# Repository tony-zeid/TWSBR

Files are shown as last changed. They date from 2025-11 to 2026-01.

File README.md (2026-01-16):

# Two‑Wheeled Self‑Balancing Robot (TWSBR)

PID‑controlled, two‑wheeled self‑balancing robot built on Arduino Uno with an MPU6050 IMU, motor encoders, and optional Bluetooth for parameter updates. 

## Features
- Balance via cascaded PID controllers (position → balance → heading)
- MPU6050 sensor fusion (complementary filter) for roll/pitch/yaw
- Quadrature encoder support with interrupts per motor
- Modular drivers for motors, pins, messaging, and Bluetooth
- PlatformIO project for reproducible build and upload

## Hardware
- Arduino Uno (ATmega328P)
- 2 × DC gear motors with quadrature encoders
- Dual H‑bridge motor driver (e.g. L298N/L9110S/compatible)
- IMU: MPU6050 (I²C)
- Optional HC‑05/HC‑06 Bluetooth module
- 7–12V battery pack with suitable regulator for logic and motors

### Pinout (Arduino Uno)
- Motors (PWM/direction)
	- MOT1_A: D6, MOT1_B: D5
	- MOT2_A: D10, MOT2_B: D11
- Encoders (interrupt channels)
	- ENC1_A: D3, ENC1_B: D13
	- ENC2_A: D2, ENC2_B: D12
- Bluetooth (optional)
	- BT_RX_PIN: D7, BT_TX_PIN: D8
- I²C (MPU6050)
	- SDA: A4, SCL: A5

Refer to the constants in include/pins.h if you change wiring.

## Wiring Table
| Subsystem | Signal | Arduino Pin | Constant | Notes |
|---|---|---|---|---|
| Motor driver | Motor 1 A (PWM/dir) | D6 | MOT1_A | Connect to driver input for M1 phase A |
| Motor driver | Motor 1 B (PWM/dir) | D5 | MOT1_B | Connect to driver input for M1 phase B |
| Motor driver | Motor 2 A (PWM/dir) | D10 | MOT2_A | Connect to driver input for M2 phase A |
| Motor driver | Motor 2 B (PWM/dir) | D11 | MOT2_B | Connect to driver input for M2 phase B |
| Encoder 1 | Channel A (INT1) | D3 | ENC1_A | Attach to encoder A; interrupt on rising edge |
| Encoder 1 | Channel B | D13 | ENC1_B | Direction sense |
| Encoder 2 | Channel A (INT0) | D2 | ENC2_A | Attach to encoder A; interrupt on rising edge |
| Encoder 2 | Channel B | D12 | ENC2_B | Direction sense |
| Bluetooth (optional) | Module TX → Uno | D7 | BT_RX_PIN | HC‑05 TX to Uno D7 |
| Bluetooth (optional) | Module RX ← Uno | D8 | BT_TX_PIN | Use resistor divider for HC‑05 RX |
| IMU MPU6050 | SDA | A4 | — | I²C data |
| IMU MPU6050 | SCL | A5 | — | I²C clock |
| IMU MPU6050 | VCC | 3.3V/5V | — | Depends on breakout (often 5V tolerant) |
| IMU/Logic | GND | GND | — | Common ground for all modules |

## Project Structure
- include/
	- IMU_functions.h — IMU addresses and public IMU API
	- bluetooth.h — Bluetooth helpers (initialise/read)
	- command.h — command handling and parameter getters
	- control_sys.h — PID gains and control loop APIs
	- messages.h — serial/Bluetooth printing utilities
	- motor_driver.h — motor actuation API
	- pins.h — pin definitions and `setupPins()`
- src/
	- IMU_functions.cpp — IMU initialisation, sensitivity config, readout, error calibration
	- bluetooth.cpp — parameter getters and Bluetooth stubs
	- control_sys.cpp — PID controllers and cascade to motor outputs
	- main.cpp — application entrypoint, run modes, telemetry
	- messages.cpp — printing helpers
	- motor_driver.cpp — PWM and direction control with fail‑safes
	- pins.cpp — pin modes and interrupt attachment
- platformio.ini — board and framework configuration

## Build, Upload, Monitor
This project uses PlatformIO. In VS Code with the PlatformIO extension:

```bash
platformio run                 # Build
platformio run --target upload # Upload to Arduino Uno
platformio device monitor -b 19200 # Open serial monitor
```

Serial baud is 19200 (required for stable MPU6050 operation in this project). Bluetooth baud is 9600 (HC‑05/HC‑06 default).

## Command Interface
The firmware accepts simple newline‑terminated commands from either the Serial Monitor (19200 baud) or the Bluetooth link (9600 baud). Commands update run mode, debug mode, PID parameters, and telemetry rate at runtime.

### Commands
- Run mode
	- `mode 0` — measure only
	- `mode 1` — run controllers (no motor drive)
	- `mode 2` — full operation (drive motors)
- Debug/print mode
	- `debug 0` — compact output (roll pitch yaw, space‑separated)
	- `debug 1` — verbose output (all diagnostics and parameters)
- Telemetry rate
	- `rate <cycles>` — print every N cycles (applies to current debug mode independently)
- Position PID
	- `poskp <value>` — proportional gain
	- `poski <value>` — integral gain
	- `poskd <value>` — derivative gain
	- `posset <value>` — setpoint
- Balance PID
	- `balkp <value>` — proportional gain
	- `balki <value>` — integral gain
	- `balkd <value>` — derivative gain
	- `balset <value>` — setpoint
- Heading PID
	- `hdgkp <value>` — proportional gain
	- `hdgki <value>` — integral gain
	- `hdgkd <value>` — derivative gain
	- `hdgset <value>` — setpoint
- IMU Calibration
	- `cal` — calibrate IMU (robot upright on wheels)
	- `cal_inv` — calibrate IMU (robot upside-down on flat top)
- Status
	- `status` — print a simple OK message

**Note:** All parameter changes (PID gains, modes, rates) and calibration results are automatically saved to EEPROM and persist across reboots.

### Examples
```
# Serial Monitor – verbose with default rate (every 500 cycles):
debug 1
mode 2
balkp 2.0

# Serial Monitor – compact output for tuning (every 10 cycles):
debug 0
rate 10
mode 2

# Bluetooth – switch to verbose, adjust a parameter:
debug 1
poskp 0.5
rate 100
```

## Run Modes & Debug Modes
`runMode` controls algorithm behaviour:
- 0 — Measure only (reads IMU and prints diagnostics)
- 1 — Run controllers (compute control signals, do not drive motors)
- 2 — Drive motors (full operation with motor control)

`debugMode` controls telemetry output:
- 0 — **Compact**: prints roll, pitch, yaw only (space‑separated, one per line) – useful for live tuning via terminal or data logging
- 1 — **Verbose**: prints all parameters, control signals, motor outputs, and diagnostics – useful for development and debugging

Each debug mode has its own independent `dataRate` (cycles per print). Use `rate` command to tune telemetry frequency per mode.

## Control Parameters
PID gains live in include/control_sys.h:
- Balance (critical): `BAL_KP`, `BAL_KI`, `BAL_KD`, `BAL_SETPOINT`
- Position: `POS_KP`, `POS_KI`, `POS_KD`, `POS_SETPOINT`
- Heading: `HDG_KP`, `HDG_KI`, `HDG_KD`, `HDG_SETPOINT`

At runtime the firmware exposes read‑only parameter blocks via:
- `getPosParam()`, `getBalParam()`, `getHdgParam()`

Bluetooth hooks (`readBtSerial()`, `updateVar()`) are scaffolded for future use but disabled by default (SoftwareSerial lines commented). To experiment, enable the commented SoftwareSerial initialisation and message prints in src/main.cpp and src/messages.cpp.

## IMU Setup and Calibration
On startup the firmware:
1. `imuInitialise()` — wakes the IMU and resets it
2. `imuConfigSensitivity()` — sets accel/gyro full‑scale ranges (configurable via `ACCEL_FSR` and `GYRO_FSR` in `include/IMU_functions.h`)
3. Calibration is now done via command, not automatically on boot

### Manual Calibration Commands
**Normal calibration (robot upright on wheels):**
```
cal
```
Keep the robot completely still and level for 2 seconds. Errors are saved to EEPROM and persist across reboots.

**Upside-down calibration (robot on flat top):**
```
cal_inv
```
Place robot on its flat top surface, level and still. This inverts accelerometer error measurements so the robot works correctly when flipped right-side-up. After calibration, flip the robot and restart for normal operation.

### Configuring IMU Full-Scale Ranges
Edit `include/IMU_functions.h` to change sensor ranges:
- `ACCEL_FSR`: 0 (±2g), 1 (±4g), 2 (±8g), 3 (±16g)
- `GYRO_FSR`: 0 (±250°/s), 1 (±500°/s), 2 (±1000°/s), 3 (±2000°/s)

Divisors update automatically when you change these values.

## PID Tuning Guide (Ziegler-Nichols Method)

### Prerequisites
Before tuning:
1. Ensure hardware is verified (encoders working, motors correct direction)
2. Calibrate IMU using `cal` or `cal_inv` command
3. Lift wheels off ground for initial testing

### Step 1: Find Critical Gain (Proportional Only)
Start with pure proportional control:
```
balkp 1.0
balki 0.0
balkd 0.0
debug 0
rate 10
mode 2
```

Gradually increase `balkp` by 0.5 until the robot oscillates **steadily** (constant amplitude):
- Too low: Robot falls immediately
- Critical gain (`Kp_crit`): Sustained oscillations without growing or decaying
- Too high: Violent oscillations that grow rapidly

**Record:**
- `Kp_crit` = value where oscillations are steady
- `T_osc` = period between peaks (count cycles, multiply by sample time)

### Step 2: Calculate PID Gains
Using Ziegler-Nichols PID formula:
```
Kp = 0.6 × Kp_crit
Ki = 1.2 × Kp_crit / T_osc
Kd = 0.075 × Kp_crit × T_osc
```

**Example:**
If `Kp_crit = 5.0` and `T_osc = 0.5s`:
```
balkp 3.0    # 0.6 × 5.0
balki 12.0   # 1.2 × 5.0 / 0.5
balkd 0.19   # 0.075 × 5.0 × 0.5
```

### Step 3: Fine-Tune
Apply calculated gains and observe:
- **Too much overshoot (>20°)?** Reduce `balkp` by 10-20%
- **Steady-state error (drifts)?** Increase `balki` slightly (by ~0.02)
- **High-frequency oscillations/chatter?** Increase `balkd` for damping
- **Sluggish response?** Increase `balkp` by 10%

### Recommended Starting Points
If you want to skip the calculation:
```
balkp 2.5    # Moderate response
balki 0.1    # Prevents drift
balkd 0.05   # Light damping
```

Then tune by feel:
- Increase `balkp` until it responds quickly but doesn't overshoot badly
- Add `balki` only if robot drifts slowly when balanced
- Increase `balkd` if robot oscillates after disturbance

### Quick Test Commands
```
# Test step response
balset 2.0   # Lean forward 2°, should recover smoothly

# Test disturbance rejection
# Gently push robot, should return to vertical in < 0.5s

# Monitor performance
debug 1
rate 1       # Print every cycle for detailed analysis
```

## Code Conventions
- Functions/variables: lowerCamelCase (e.g. `runMode`, `setupPins`, `balanceControl`)
- Constants/macros: UPPER_SNAKE_CASE (e.g. `MOT1_A`, `IMU_GYRO_DATA`)
- Types: PascalCase

## Safety Features
- **Safety Cutoff:** Motors automatically cut if tilt exceeds ±45° (prevents damage during pickup or falls)
- **Motor Clamping:** PWM outputs clamped to 0–255
- **Direction Safety:** Direction pins clear before switching to prevent shoot-through
- **Encoder Deadband:** ±2 tick deadband prevents noise-induced motor chatter

**Testing Safety:**
- Lift wheels off ground during initial tests
- Ensure power rails are stable; brown‑outs can cause runaway behaviour
- Use foam padding when testing autonomous balance

## Memory Usage and Optimization Notes

**Current RAM Usage: ~88% (1808/2048 bytes)**

The Arduino Uno has only 2KB of RAM, and this project uses:
- **~450 bytes**: Arduino libraries (Serial, Wire/I²C, SoftwareSerial)
- **~200 bytes**: Global variables (control arrays, IMU state, motor state)
- **~1000 bytes**: Arduino core overhead (timers, interrupts, system buffers)
- **~240 bytes free**: Available for stack during runtime

### Recent Optimizations
Several RAM optimizations have been applied to reduce memory pressure:

1. **String → char array conversion**: Replaced `String` objects with fixed-size `char[64]` buffers for serial/Bluetooth input (~60-80 bytes saved)
2. **Bit-packed mode flags**: Packed `runMode`, `debugMode`, and `printData` into a single byte using bit fields (2 bytes saved)
3. **Local variables for controller outputs**: Changed `posOut`, `balOut`, `hdgOut` from static globals to local variables (12 bytes saved)
4. **Direct AVR EEPROM access**: Replaced Arduino EEPROM library with `<avr/eeprom.h>` functions (eliminates library overhead)

**Total RAM savings: ~95 bytes** (from 95.3% → 88.7% usage including safety cutoff feature)

### IMU Configuration
The IMU full-scale ranges are now configurable at compile-time in `include/IMU_functions.h`:
- `ACCEL_FSR`: 0-3 (±2g, ±4g, ±8g, ±16g) - currently set to 2 (±8g)
- `GYRO_FSR`: 0-3 (±250°/s, ±500°/s, ±1000°/s, ±2000°/s) - currently set to 2 (±1000°/s)

Divisors are automatically calculated based on these settings.

### EEPROM Implementation
This project uses direct AVR EEPROM functions (`eeprom_read_byte()` and `eeprom_write_byte()` from `<avr/eeprom.h>`) instead of the Arduino EEPROM library. This approach:
- Eliminates library RAM overhead
- Provides explicit control over EEPROM operations
- Saves ~50-100 bytes compared to the Arduino library

All parameters (PID gains, modes, IMU calibration) persist across reboots via EEPROM.

**Current Status:**
With 240 bytes of free stack space, there is adequate headroom for runtime operations. The control loops avoid deep recursion and large local variables, keeping stack usage minimal.

## Tuning the Control Loops

### Overview
The robot uses a cascaded control structure: **Position** → **Balance** → **Motors**. Tuning follows a bottom‑up approach starting with balance (most critical), then position and heading.

### Balance Loop (Critical)
The balance loop corrects tilt (pitch) to keep the robot upright. **Start here first.**

#### Phase 1: Controller Sanity Check (Mode 1, wheels lifted)
1. **Lift wheels off the ground** and hold robot level
2. Set `mode 1` (controllers run, motors disabled) and `debug 1` (verbose output)
3. Start with small gains: `balkp 1.0`, `balki 0.0`, `balkd 0.0`
4. **Tilt robot forward** and observe the **motor command output** in telemetry:
   - Controller should output positive PWM (trying to drive forward to correct)
   - Larger tilt → larger PWM (proportional response)
5. **Tilt robot backward** and verify opposite response (negative/reverse motor command)
6. If signs are wrong, swap motor direction pins or invert controller logic

#### Phase 2: Initial Balance Test (Mode 2, wheels on ground)
7. **Place robot on flat surface** with wheels on ground
8. Set `mode 2` (full operation, motors enabled)
9. **Hold robot upright** and release gently:
   - Robot should attempt to balance (may fall at first)
   - Observe for oscillation, divergence, or stability
10. If robot falls immediately:
    - Reduce `balkp` by 50% and retry
    - Verify motor directions are correct (both should spin same direction when tilting forward)
11. If robot oscillates slowly (growing):
    - Increase `balkp` by 20–50%
12. If robot oscillates rapidly (high frequency):
    - Reduce `balkp` or add small `balkd` (start 0.02)

#### Phase 3: Fine-Tuning
13. Once robot balances briefly (even 1–2 seconds), tune for stability:
    - Increase `balkp` until oscillation just begins, then back off 10–20%
    - Add `balki` (0.05–0.1) only if robot drifts slowly in one direction
    - Add `balkd` (0.02–0.05) if high-frequency vibration appears
14. Use compact telemetry for real-time feedback: `debug 0`, `rate 10`
15. Test by gently pushing robot forward/backward; it should recover smoothly

**Typical starting gains**: `balkp 2.0`, `balki 0.1`, `balkd 0.03` (highly robot-dependent)

### IMU Drift Issue
If IMU pitch/roll drifts after movement and doesn't return to zero:
- **Re-calibrate IMU** (keep robot level and still during startup)
- **Check complementary filter** (currently in `IMU_functions.cpp`, typically 0.98–0.99 gyro weight)
- **Gyro drift** is normal over time; re-calibration or magnetometer fusion helps

### Position Loop (Once Balance Works)
Position loop maintains forward/backward centering. The balance loop naturally provides position feedback via roll change.

1. Switch to `mode 2` with wheels still lifted (motor PWM will run but wheels won't turn much).
2. Observe whether the robot tends to "creep" forward or backward in pitch.
3. Adjust `poskp` (start ~0.5–1.0) and `poski` (~0.05) if systematic drift appears.
4. Most robots need minimal position tuning if balance loop is good.

### Heading Loop (Fine‑Tuning)
Heading loop corrects yaw. Usually requires minimal tuning for forward motion.

1. With the robot on a flat surface (wheels on ground), switch to `mode 2`.
2. Watch yaw drift; if the robot consistently turns left/right, adjust `hdgkp` and `hdgki` slightly.
3. Most setups work well with `hdgkp 1.0`, `hdgki 0.0`, `hdgkd 0.0`.

### Practical Workflow
```bash
# 1. Verify controller sign (mode 1, wheels lifted)
debug 1
mode 1
balkp 1.0
balki 0.0
balkd 0.0
# Tilt forward/backward and observe motor commands in telemetry

# 2. Initial balance test (mode 2, wheels on ground)
mode 2
# Hold upright and release; adjust balkp until stable

# 3. Switch to compact telemetry for live tuning
debug 0
rate 10

# 4. Fine-tune gains
balkp 2.0      # Adjust until oscillation just stops
balki 0.1      # Add if slow drift appears
balkd 0.03     # Add if high-frequency vibration

# 5. If IMU drifts, re-calibrate by restarting with robot level
# (or adjust complementary filter in IMU_functions.cpp)
```
rate 100
```

### Monitoring Telemetry
- **Compact mode** (`debug 0`): Three space‑separated floats per line: roll pitch yaw. Pipe to a file for post‑analysis.
  ```bash
  # Example: log data for 30 seconds at 19200 baud
  cat /dev/ttyUSB0 > data.txt &
  # ... run tuning commands ...
  # Ctrl+C to stop
  gnuplot -e "plot 'data.txt' u 2" # Plot pitch over time
  ```
- **Verbose mode** (`debug 1`): Full diagnostics; easier for real‑time observation but slower telemetry.

### If Robot Oscillates or Diverges
- **High‑frequency oscillation**: Reduce Kd or Kp; IMU noise may be coupling back.
- **Low‑frequency / growing oscillation**: Reduce Ki; integral term may be accumulating too fast.
- **Divergent (unstable)**: Cut all gains by half and restart. Check motor/encoder wiring.

### If Robot Falls Sideways
- Verify IMU calibration: run `mode 0` and confirm roll ≈ 0 when level.
- Check that motors spin in the correct directions (balance loop commands opposite motors for correction).
- Verify encoder counts are correct (see Troubleshooting).

## Troubleshooting
- No serial output: check the monitor baud is 19200.
- IMU values stuck or wild: verify SDA/SCL wiring and 5V↔3.3V compatibility of your module.
- Encoders count backwards: swap encoder B signal or invert in `inc1()/inc2()`.
- Motors spin but no balance: start tuning with balance Kp small (e.g. 2.0) and Ki/Kd near zero, then iterate.

## Acknowledgements
IMU routines adapted from Dejan Nedelkovski (howtomechatronics.com).

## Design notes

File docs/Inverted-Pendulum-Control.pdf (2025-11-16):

# Dynamics and Control of Inverted Pendulum Systems

## 1 Standard Inverted Pendulum on a Cart

### 1.1 System Description

- Cart mass: M
- Pendulum mass: m
- Pendulum length to CoM: l
- Gravity: g
- Horizontal force input: F
- x: horizontal position of the cart
- θ: pendulum angle from vertical (clockwise positive)

### 1.2 Nonlinear Equations of Motion

(M + m)¨x + ml¨θ cos θ − ml ˙θ
2
sin θ = F | (1)
mlx¨ cos θ + ml² ¨θ − mglsin θ = 0 | (2)

### 1.3 Nonlinear State-Space Model

Define state vector and input:

x =

x
x˙
θ
˙θ

, u = F

Express the system as:

x˙ =

x˙
x¨
˙θ
¨θ

= f(x, u)

To solve for ¨x and ¨θ, rewrite (1), (2) in matrix form:
M + m ml cos θ
ml cos θ ml²

| | {z | }
| D(θ)
x¨
¨θ
=

u + ml ˙θ
2
sin θ
mglsin θ

Then:
x¨
¨θ
= D(θ)

−1

u + ml ˙θ
2
sin θ
mglsin θ

Hence the nonlinear state-space model is:

x˙ =

x˙
x¨(x, u)
˙θ
¨θ(x, u)

—

## 2 Wheeled Inverted Pendulum (Self-Balancing Robot)

### 2.1 System Description

- Wheel mass: M, radius R, inertia Iw
- Pendulum mass: m, pendulum CoM length: l, inertia Ip
- Gravity: g
- Torque input: τ (applied to wheel)
- x: horizontal position of wheel
- θ: pendulum angle from vertical (clockwise positive)

### 2.2 Nonlinear Equations of Motion

M + m +

Iw
R²
x¨ + ml¨θ cos θ − ml ˙θ
2
sin θ =

τ
R

(3)

mlx¨ cos θ +

Ip + ml²
¨θ − mglsin θ = 0 | (4)

### 2.3 Nonlinear State-Space Model

Define

x =

x
x˙
θ
˙θ

, u = τ

Rewrite (3), (4) as:

D(θ) =
M + m +

Iw
R² | ml cos θ
ml cos θ | Ip + ml²
, b =
u

R + ml ˙θ
2
sin θ
mglsin θ

Then
x¨
¨θ
= D(θ)

−1b

The nonlinear state-space form is

x˙ =

x˙
x¨(x, u)
˙θ
¨θ(x, u)

—

## 3 Linearized Models and State-Space Form

### 3.1 Linearized Dynamics for Cart Pendulum

Linearize around θ = 0, ˙θ = 0:

sin θ ≈ θ, cos θ ≈ 1

Linearized equations:
M + m ml
ml ml²

x¨
¨θ
=
u

mglθ

Explicitly:

(M + m)¨x + ml¨θ = u

mlx¨ + ml² ¨θ − mglθ = 0

### 3.2 Linearized State-Space Form for Cart Pendulum

Define state:

x =

x
x˙
θ
˙θ

, u = F

The linear state-space model is:

x˙ = Ax + Bu

Where

A =

0 1 | 0 | 0
0 0 | −
| mgl M | 0
0 0 | 0 | 1

0 0 (M+m)g
| M l | 0

, B =

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
### 3.3 Linearized Dynamics for Wheeled Inverted Pendulum

Linearize around θ = 0, ˙θ = 0:

sin θ ≈ θ, cos θ ≈ 1

D =

α | ml
ml | β

with

α = M + m +

Iw
R²

, β = Ip + ml²

Linearized equations:
α | ml
ml | β x¨ ¨θ
=

u
R

mglθ

—

### 3.4 Linearized State-Space Form for Wheeled Pendulum

State vector:

x =

x
x˙
θ
˙θ

, u = τ

State-space model:

x˙ = Ax + Bu

with

A =

0 1 | 0 | 0
0 0 − | m²gl² ∆R | 0
0 0 | 0 | 1
0 0 | mglα ∆ | 0

, B =

0

β
∆R
0
−

ml
∆

where the determinant

∆ = αβ − (ml)

2

—

## 4 Controller Design

### 4.1 PID Control

For both systems, a PID controller can be used to regulate the pendulum angle:

u(t) = Kpe(t) + Ki

Z
e(t)dt + Kd

de(t)
dt , e(t) = θref − θ(t)

Tuning methods (Ziegler-Nichols, manual) apply.

### 4.2 LQR Control

Given linearized models:

x˙ = Ax + Bu, u = −Kx

The gain matrix K minimizes

J =

Z ∞

0

| x | TQx + u

TRu
dt

where Q and R are weighting matrices chosen by the designer. K is computed by solving the algebraic Riccati equation.
—

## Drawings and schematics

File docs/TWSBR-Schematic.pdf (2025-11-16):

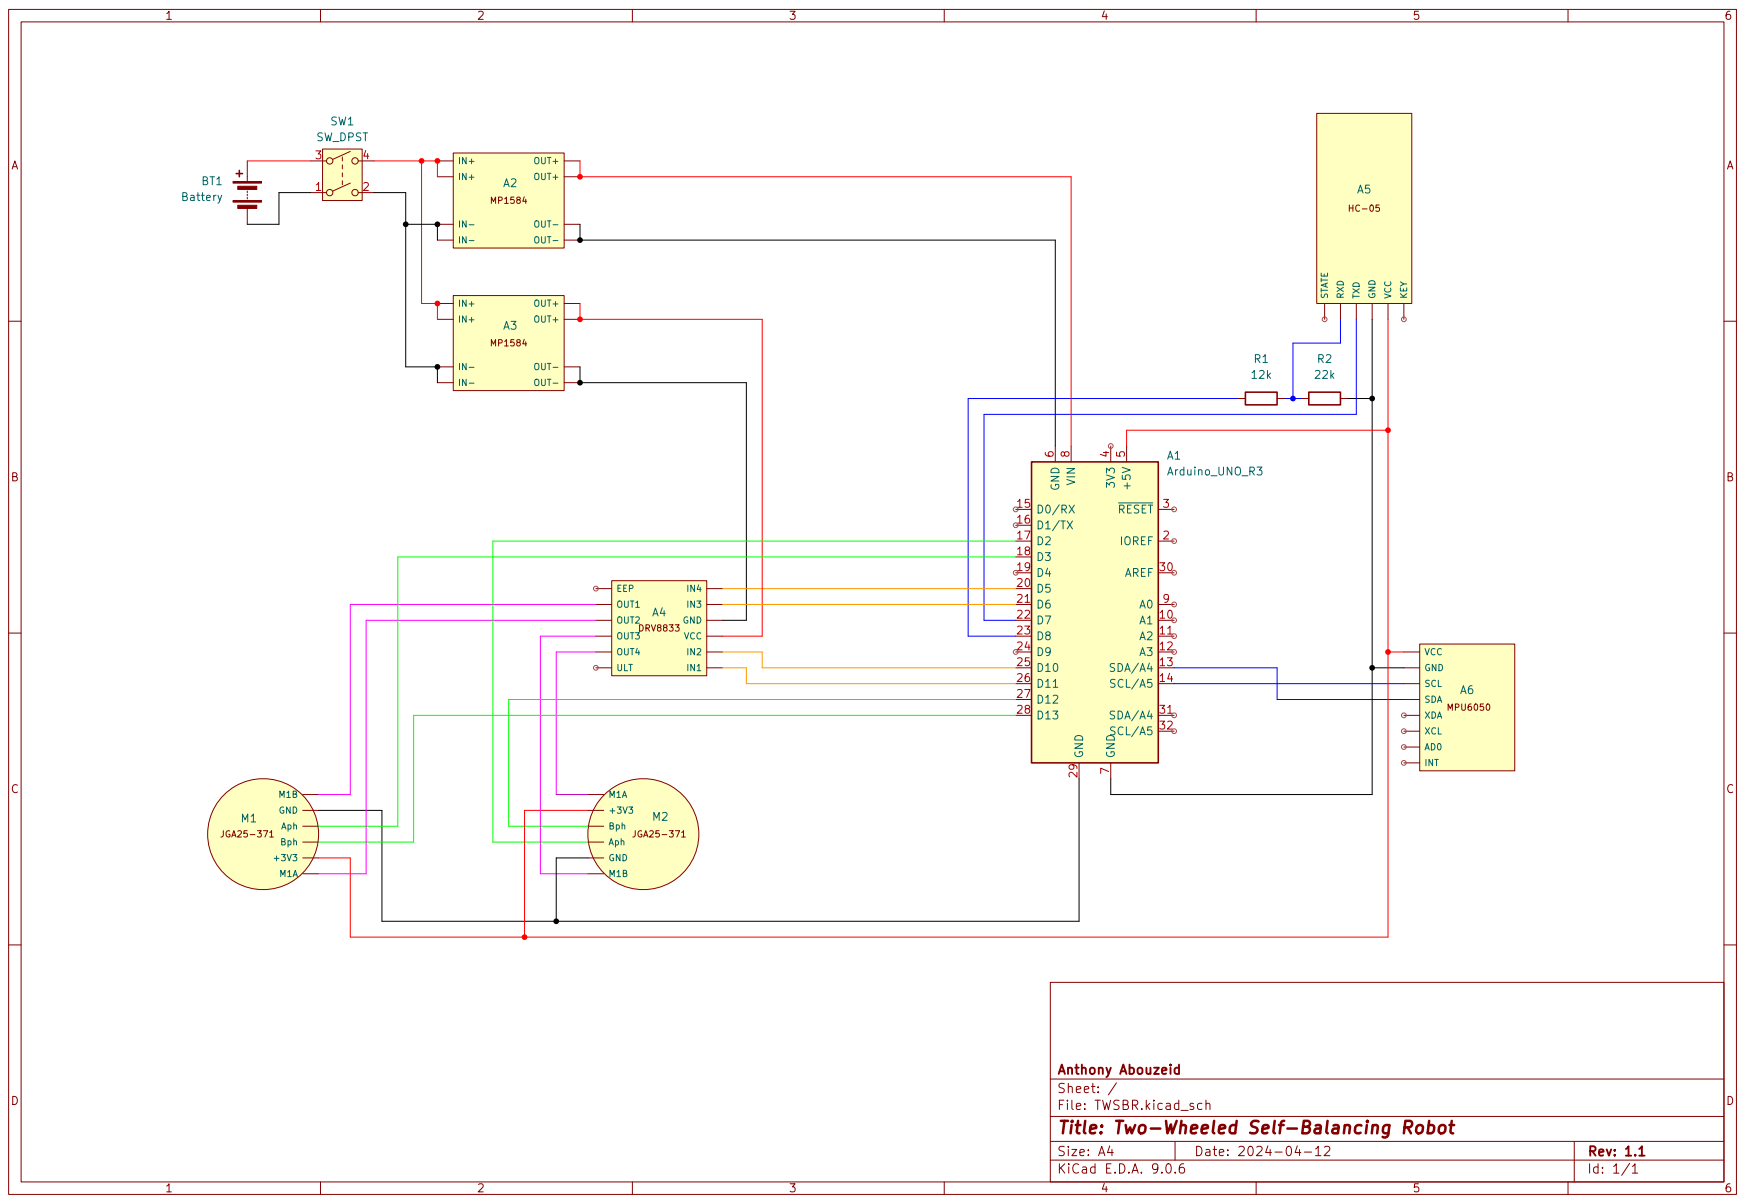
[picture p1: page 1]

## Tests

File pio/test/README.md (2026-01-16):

# TWSBR Test Suite

This directory contains tests for the TWSBR firmware.

## Test Organization

All tests are in the `test/` folder with naming conventions:
- **test_\*.cpp** — Native PC tests (command parsing, control math, validation)
- **test_hw_\*.cpp** — Arduino Uno hardware tests (EEPROM, motors, encoders, IMU)
- **test_support.\*** — Shared test infrastructure for native tests

## Running Tests

### Native tests only (PC)
```bash
platformio test -e native -v
```

### Hardware tests only (requires Arduino Uno)
```bash
platformio test -e uno -v
```

### Specific test
```bash
platformio test -e uno -f test_hw_motors -v
platformio test -e native -f test_command -v
```

## Native Test Suite

Tests for command parsing, control logic, and parameter validation—run on PC without hardware.

### Test Files

- **test_command.cpp** — command parsing, mode changes, parameter updates
- **test_control.cpp** — PID math, motor clamping, numerical stability
- **test_validation.cpp** — bounds checking, realistic ranges
- **test_runner.cpp** — unified test entry point with setUp/tearDown
- **test_support.h/cpp** — shared mocks and helpers (Arduino types, String, command logic)

### Coverage

- **Command Parser** (~12 tests): mode, debug, rate, PID parameter updates, error handling
- **Control Logic** (~8 tests): proportional/integral/derivative response, motor output clamping
- **Parameter Validation** (~5 tests): gain ranges, setpoint bounds, mode validity

## Uno Test Suite

Tests for hardware integration and EEPROM persistence—run on Arduino Uno.

### Test Files

- **test_hw_eeprom.cpp** — EEPROM save/load, parameter persistence, validation
- **test_hw_motors.cpp** — motor control, PWM, direction, simultaneous drive
- **test_hw_encoders.cpp** — encoder pin initialization, state reading
- **test_hw_imu.cpp** — IMU initialization, sensitivity config, error calibration

### Coverage

- **EEPROM** (~11 tests): save/load runMode/debugMode/dataRate/PID gains, corruption recovery, roundtrip
- **Motors** (~7 tests): forward/backward, PWM range, simultaneous drive, stop
- **Encoders** (~2 tests): pin initialization, state reading
- **IMU** (~5 tests): initialization, sensitivity config, error calibration, data bounds

### Calibration

See [CALIBRATION.md](CALIBRATION.md) for comprehensive hardware calibration procedures:
- **IMU calibration**: level placement, error bounds, troubleshooting
- **Encoder calibration**: direction verification, pin testing
- **Motor direction**: balance verification, reversal procedures
- **PID tuning**: balance loop, position loop, heading loop
- **Verification**: hardware tests, soak testing

## Future Additions (ideas)
- Hardware smoke on `env:uno`: build/link and a tiny runtime check that default `runMode`/`debugMode` are sane.
- Compact-output contract: assert `debug 0` emits `roll pitch yaw\n` (spaces, trailing newline, no commas/brackets).
- Telemetry rate behavior: verify `rate` only updates the active `debugMode` slot and `printData` toggles correctly over multiple cycles.
- Command fuzzing: randomized long/short/malformed commands to ensure parser never corrupts state or crashes.
- Bluetooth/serial parity (hardware): commands over BT behave identically to serial, both verbose and compact.
- Soak test: multi-minute loop run (motors disabled or wheels lifted) to catch resets or memory creep.

## Example: Adding a New Test

```cpp
void test_new_feature(void) {
    // Arrange
    int input = 42;
    int expected = 84;
    
    // Act
    int result = double(input);
    
    // Assert
    TEST_ASSERT_EQUAL_INT(expected, result);
}
```

## Continuous Integration

To run tests as part of your build pipeline:
```bash
platformio ci --lib="./lib" --lib="./include" --project-conf=platformio.ini
```

## Troubleshooting

- **Test won't compile**: Ensure mocks for `Serial`, `printMsg`, and control functions match your actual signatures
- **Floating point assertions fail**: Use `TEST_ASSERT_FLOAT_WITHIN(tolerance, expected, actual)` for comparisons
- **Extern variable errors**: Declare `extern` variables at the top of test files; ensure they match main.cpp definitions

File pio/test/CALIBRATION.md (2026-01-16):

# Hardware Calibration Procedure

This guide covers calibrating the IMU, motor encoders, and motor directions for the TWSBR.

## IMU Calibration

The IMU (MPU6050) requires calibration to measure steady-state accelerometer and gyroscope offsets. These are subtracted from all readings to center the measurements around zero.

### Procedure

1. **Physical Setup**
   - Place the robot on a flat, level surface
   - Keep it completely **still and level** (±2° tilt acceptable)
   - Ensure nothing is vibrating or moving

2. **Power On & Boot**
   - Upload firmware: `platformio run -e uno --target upload`
   - Open Serial Monitor at **19200 baud**: `platformio device monitor -b 19200`
   - Wait for startup messages:
     ```
     [INIT] Serial
     [INIT] IMU Start
     [INIT] IMU Scale
     [INIT] IMU Config
     [INFO] IMU Errors
     AccErrX: <value>
     AccErrY: <value>
     GyrErrX: <value>
     GyrErrY: <value>
     GyrErrZ: <value>
     ```

3. **Verify Calibration**
   - Accelerometer errors (AccErrX, AccErrY) should be **< 0.5g** (ideally near zero)
   - Gyroscope errors (GyrErrX/Y/Z) should be **< 5 deg/s** (ideally near zero)
   - If errors are large, check:
     - Robot is truly level (use a bubble level if available)
     - No vibrations from nearby fans, motors, etc.
     - MPU6050 is rigidly mounted (not loose)

4. **Good Calibration Example**
   ```
   [INFO] IMU Errors
   AccErrX: 0.12
   AccErrY: -0.08
   GyrErrX: 1.2
   GyrErrY: -0.8
   GyrErrZ: 2.1
   ```

5. **If Calibration Fails**
   - Errors > 1g or > 10 deg/s suggest:
     - **Tilted placement**: Use a level; tilt introduces accel bias
     - **Vibration**: Move robot away from speakers, fans, running motors
     - **Sensor malfunction**: Verify I²C wiring (SDA/SCL) and 3.3V power
     - **Bad solder joint**: Check MPU6050 module for loose connections

## Encoder Calibration

Encoders measure motor speed and direction. Proper calibration ensures accurate position control.

### Procedure

1. **Pin Verification**
   - Verify encoder connections in `include/pins.h`:
     ```cpp
     #define ENC1_A D3  // Motor 1, Channel A
     #define ENC1_B D13 // Motor 1, Channel B
     #define ENC2_A D2  // Motor 2, Channel A
     #define ENC2_B D12 // Motor 2, Channel B
     ```
   - Check physical wiring to motor modules

2. **Direction Test**
   - Set robot in **mode 0** (measure only): `mode 0`
   - Watch encoder outputs in verbose mode: `debug 1` and `rate 100`
   - Manually spin motor 1 forward; verify encoder counts increase
   - Manually spin motor 1 backward; verify encoder counts decrease
   - Repeat for motor 2

3. **If Direction Is Reversed**
   - Swap encoder A and B channels in the motor module (physical rewiring)
   - OR invert in firmware by swapping the interrupt handlers (`inc1()` / `inc2()`) if needed

4. **If No Counts Register**
   - Check encoder power (usually 5V on motor module)
   - Verify I/O pins are not shorted or floating
   - Test with `digitalWrite()` and `digitalRead()` on the encoder pins
   - Ensure interrupt is attached correctly in `setupPins()`

## Motor Direction Calibration

Motors must spin in opposite directions for balance. If both spin the same way, the robot cannot correct tilt.

### Procedure

1. **Set Mode & Disable Motors**
   - Set `mode 1` (run controllers but don't drive motors yet)
   - Lift wheels off the ground

2. **Manual Direction Check**
   - Tilt the robot forward slightly in your hand
   - Observe the motor PWM signals (verbose telemetry shows motor commands)
   - Motor 1 should want to drive **forward** (pitch error is positive)
   - Motor 2 should want to drive **backward**
   - If reversed, swap motor A and B direction pins or reverse firmware logic

3. **Automated Test (Optional)**
   - Run hardware test: `platformio test -e uno -v`
   - Tests verify motor PWM can be applied without error

4. **If Motor Directions Are Wrong**
   - Physically swap the power leads (swap + and − terminals) on one motor, OR
   - Modify firmware to invert the PWM pins for that motor

## Control Parameter Calibration

Once hardware is calibrated, tune PID gains (see [README.md](../../README.md#tuning-the-control-loops) for detailed steps).

### Quick Start

1. **Balance Loop (Critical)**
   - Start with `balkp 0.5`, `balki 0.05`, `balkd 0.02`
   - Tilt robot gently; watch it oscillate and settle
   - Increase Kp until response is fast but not oscillating
   - Increase Ki slightly if drift persists
   - Increase Kd if high-frequency noise appears

2. **Position Loop**
   - Usually works well if balance is tuned
   - Adjust `poskp` and `poski` only if forward/backward creep is visible

3. **Heading Loop**
   - Minimal tuning; `hdgkp 1.0` often sufficient
   - Adjust if robot consistently turns left/right

## Testing & Verification

### Run Hardware Tests
```bash
# Compile and run motor/encoder/IMU tests on Arduino
platformio test -e uno -v
```

Tests will verify:
- Motor PWM and direction control
- Encoder pins are readable
- IMU initialization and calibration
- Calibration values are within bounds

### Soak Test
After calibration:
1. Set `mode 2` (full operation)
2. Lift wheels and let robot balance in your hand for 1–2 minutes
3. Monitor telemetry; observe for:
   - Smooth, stable response (no oscillation)
   - Consistent roll/pitch/yaw (no drift)
   - No watchdog resets or crashes

## Troubleshooting

| Symptom | Cause | Fix |
|---|---|-----|
| Robot falls forward/backward immediately | Poor balance tuning or wrong motor direction | Increase Kp slowly; verify motors spin correctly |
| Robot oscillates and diverges | Kp too high or Ki accumulating | Reduce Kp by 50%; add anti-windup or cap Ki |
| Motors don't respond to commands | Motor driver not powered or pins misconfigured | Check 12V supply to motor driver; verify pin definitions |
| Encoders stuck at zero | Encoder pins not connected or interrupt not firing | Check physical wiring; use `digitalWrite`/`digitalRead` to test |
| IMU errors very large (>1g accel, >10 deg/s gyro) | Poor calibration or sensor malfunction | Re-calibrate with robot level; check I²C wiring |
| Yaw drifts continuously | Heading loop not tuned or gyro Z bias large | Increase `hdgki` slightly; re-calibrate IMU |

## Next Steps

After successful calibration:
1. **Field test** with wheels on ground (lift slightly to avoid sharp turns)
2. **Tuning refinement** using compact telemetry mode (`debug 0`, `rate 10`)
3. **Parameter persistence** — parameters are saved to EEPROM automatically (`saveParametersToEEPROM()`)
4. **Bluetooth control** (optional) — same commands work over HC-05 at 9600 baud

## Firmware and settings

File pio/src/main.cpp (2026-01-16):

/*******************************************************************************
 *                                                                             
 *                Two-Wheeled Self-Balancing Robot (TWSBR)
 *                     Project using Arduing Uno              
 *
 ******************************************************************************/

// Standard libraries
#include <Arduino.h>
#include <Wire.h>
#include <SoftwareSerial.h>
#include <string.h>

// Project libraries
#include "../include/pins.h"           // Defines pinout and sets pin modes
#include "../include/messages.h"       // Prints messages & data to serial & BT
#include "../include/IMU_functions.h"  // Configure & read from IMU
#include "../include/control_sys.h"    // Runs control system calculation
#include "../include/motor_driver.h"   // Sets motor direction & PWM duty cycle
#include "../include/bluetooth.h"      // Bluetooth I/O
#include "../include/command.h"        // Command handling & parameters

// Packed mode bits (saves 2 bytes vs separate uint8_t variables)
// Bits 0-1: runMode (0-2)
// Bit 2: debugMode (0-1)
// Bit 3: printData (0-1)
uint8_t modeBits = 0x02;  // runMode=2, debugMode=0, printData=0
#define runMode       ((modeBits) & 0x03)
#define setRunMode(m) (modeBits = (modeBits & 0xFC) | ((m) & 0x03))
#define debugMode     (((modeBits) >> 2) & 0x01)
#define setDebugMode(d) (modeBits = (modeBits & 0xFB) | (((d) & 0x01) << 2))
#define printData     (((modeBits) >> 3) & 0x01)
#define setPrintData(p) (modeBits = (modeBits & 0xF7) | (((p) & 0x01) << 3))

// Program counter and data output rates per debug mode
int loopCount = 0;    // Increments on each loop
uint16_t dataRatePerMode[2] = {10, 500};  // dataRatePerMode[debugMode]
#define dataRate (dataRatePerMode[debugMode])

// Pointer to IMU error array
float *errPtr;              

// Setup Bluetooth serial
//SoftwareSerial BTSerial(BT_RX_PIN, BT_TX_PIN);

// Initialisation routines
void setup() {
    // Setup I/O pin modes and interrupts
    setupPins();
    //test_motors();    // Uncomment to test (run mode 0 only!)

    // Initialise serial and Bluetooth communications
    Serial.begin(19200);        // 19200 required for MPU6050
    printMsg("");
    printMsg("[INIT] Serial");

    // Load saved parameters from EEPROM
    loadParametersFromEEPROM();

    initBtSerial();
    
    // Initialise I2C comms and reset IMU 
    imuInitialise();
    printMsg("[INIT] IMU Start");

    // Configures sensitivity of Accel and Gyro
    imuConfigSensitivity();
    delay(20);                                                      // Delay for stability (min 20ms)
    printMsg("[INIT] IMU Scale");

    // NOTE: Calibration now done via 'cal' or 'cal_inv' commands, not on boot
    // This saves RAM and allows choosing normal or upside-down calibration
    printMsg("[INIT] IMU Ready");
    printMsg("[INFO] Use 'cal' or 'cal_inv' command to calibrate");

    // End-of-setup message
    printMsg("==================================================");
    printMsg("[STATUS] Robot Ready");
    delay(50);                                                      // Delay for stability (min 20ms)
}

// Main Control Cycle
void loop() {
    // Determines whether to print this cycle
    if (loopCount % dataRate == 0) {
        modeBits |= 0x08;  // Set printData bit
    } else {
        modeBits &= 0xF7;  // Clear printData bit
    }

    // Process Bluetooth commands if any
    readBtSerial();

    if((modeBits & 0x03) == 0 || (modeBits & 0x03) == 1 || (modeBits & 0x03) == 2) {   
        // Get current control parameters
        float *posParamPtr = getPosParam();    // Position
        float *balParamPtr = getBalParam();    // Balance
        float *hdgParamPtr = getHdgParam();    // Heading                                                             

        // Update IMU measurements, returns RPYT
        float *imuPtr = imuReadData();
        
        // SAFETY CUTOFF: Check tilt angle for safety
        // If robot tilts beyond safe limits, cut all motor outputs
        float pitch = imuPtr[1];  // Pitch angle
        float roll = imuPtr[0];   // Roll angle
        if (abs(pitch) > TILT_SAFETY_LIMIT || abs(roll) > TILT_SAFETY_LIMIT) {
            // Robot has fallen or being picked up - stop motors immediately
            int safeMotors[4] = {0, 0, 0, 0};  // All motors off
            runMotors(safeMotors);
            
            if (printData) {
                printMsg("[SAFETY CUTOFF] Tilt limit exceeded - motors stopped");
            }
            
            loopCount++;
            return;  // Skip control loop this cycle
        }

        // Continue with normal control if within safe limits
        // Compute control outputs for both compact and verbose modes
        float posOut = 0, balOut = 0, hdgOut = 0;
        int *motorActuationPtr = nullptr;
        
        if(runMode == 1 || runMode == 2){
            posOut = positionControl(imuPtr, posParamPtr, false);
            balOut = balanceControl(imuPtr, balParamPtr, posOut, false);
            hdgOut = headingControl(imuPtr, hdgParamPtr, false);
            motorActuationPtr = cascadeControl(imuPtr, balOut, hdgOut, false);
        }

        // Compact mode: print Roll, Pitch, Yaw, M1_speed, M2_speed, Enc1_pos, Enc2_pos (space-separated)
        if(debugMode == 0){
            if(printData){
                int *encPos = getMotorPositions();
                Serial.print(imuPtr[0]);    // Roll
                Serial.print(" ");
                Serial.print(imuPtr[1]);    // Pitch
                Serial.print(" ");
                Serial.print(imuPtr[2]);    // Yaw
                Serial.print(" ");
                Serial.print(motorActuationPtr ? motorActuationPtr[0] : 0);  // M1 speed
                Serial.print(" ");
                Serial.print(motorActuationPtr ? motorActuationPtr[1] : 0);  // M2 speed
                Serial.print(" ");
                Serial.print(encPos[0]);  // Encoder 1 position
                Serial.print(" ");
                Serial.println(encPos[1]);  // Encoder 2 position
            }
        }
        // Verbose mode: print full diagnostics
        else if(debugMode == 1){
            if(printData){
                printMsg("==================================================");
                printInt("Count:", &loopCount, 0);
                int timeNow = millis();
                printInt("Time:", &timeNow, 0);   
                printMsg("");
                printMsg("[INFO] Control parameters");
                // Position control parameters
                printFloat("SetPos:", posParamPtr, 0); 
                printFloat("PosKP:", posParamPtr, 1);
                printFloat("PosKI:", posParamPtr, 2);
                printFloat("PosKD:", posParamPtr, 3);
                printMsg("");
                // Balance control parameters
                printFloat("SetBal:", balParamPtr, 0);        
                printFloat("BalKP:", balParamPtr, 1);
                printFloat("BalKI:", balParamPtr, 2);
                printFloat("BalKD:", balParamPtr, 3);
                printMsg("");
                // Heading control parameters
                printFloat("SetHdg:", hdgParamPtr, 0);       
                printFloat("HdgKP:", hdgParamPtr, 1);
                printFloat("HdgKI:", hdgParamPtr, 2);
                printFloat("HdgKD:", hdgParamPtr, 3);
                printMsg("");
                printMsg("[INFO] IMU measurements");       
                // IMU measurement data
                printFloat("Time:", imuPtr, 3);   
                printFloat("Tdif:", imuPtr, 4);
                printMsg("");
                printFloat("Roll:", imuPtr, 0);                
                printFloat("Pitch:", imuPtr, 1);
                printFloat("Yaw:", imuPtr, 2);
                printMsg("");
            }
        }

        // Send RPYT to controller for motor drive signal (verbose debug mode)                                      
        if((runMode == 1 || runMode == 2) && debugMode == 1){
            // Re-compute with verbose printing enabled for verbose mode
            posOut = positionControl(imuPtr, posParamPtr, printData);                      // P/B/H controllers    
            balOut = balanceControl(imuPtr, balParamPtr, posOut, printData);
            hdgOut = headingControl(imuPtr, hdgParamPtr, printData);

            if(printData){
                printMsg("[INFO] Control signals");
                printFloat("POScon:", &posOut, 0);          // Position control output
                printFloat("BALcon:", &balOut, 0);          // Balance control output
                printFloat("HDGcon:", &hdgOut, 0);          // Heading control output
                printMsg("");
            }     

            motorActuationPtr = cascadeControl(imuPtr, balOut, hdgOut, printData);                 // Cascade controller

            // Print actuation signal values to serial monitor and Bluetooth
            if(printData){
                printMsg("[INFO] Motor output");
                printInt("M1Spd:", motorActuationPtr, 0);     
                printInt("M1Dir:", motorActuationPtr, 2);        
                printMsg("");
                printInt("M2Spd:", motorActuationPtr, 1);
                printInt("M2Dir:", motorActuationPtr, 3);
                printMsg("");
            }     
            
            // Send actuation signal to motors
            if(runMode == 2){
                runMotors(motorActuationPtr);                                                             // Run Motors
                if(printData) printMsg("[STATUS] Motors running");
            }
        }
        // Compact mode: compute control but don't print verbose output
        else if((runMode == 1 || runMode == 2) && debugMode == 0){
            float posOut = positionControl(imuPtr, posParamPtr, false);                           // Compute silently
            float balOut = balanceControl(imuPtr, balParamPtr, posOut, false);
            float hdgOut = headingControl(imuPtr, hdgParamPtr, false);
            int *motorActuationPtr = cascadeControl(imuPtr, balOut, hdgOut, false);
            if(runMode == 2){
                runMotors(motorActuationPtr);
            }
        }
    }

    // Message for run mode error
    else if (runMode != 0 && runMode != 1 && runMode != 2){
        if(printData && debugMode == 1) printMsg("[ERROR] Invalid run mode");
    }

    // Increment program counter
    ++loopCount;

    // Also process any commands typed into Serial Monitor
    processSerialCommands();
}

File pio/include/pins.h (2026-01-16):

#ifndef PINS_H
#define PINS_H

    #include <Arduino.h>
    #include "control_sys.h"

    // Motors
    #define     MOT1_A      6       // Motor 1, phase A
    #define     MOT1_B      5       // Motor 1, phase B
    #define     MOT2_A      10      // Motor 2, phase A
    #define     MOT2_B      11      // Motor 2, phase B

    // Encoders
    #define     ENC1_A      3       // Motor 1 encoder, phase A
    #define     ENC1_B      13      // Motor 1 encoder, phase B
    #define     ENC2_A      2       // Motor 2 encoder, phase A  
    #define     ENC2_B      12      // Motor 2 encoder, phase B

    // Bluetooth
    #define     BT_RX_PIN   7       // Bluetooth RX
    #define     BT_TX_PIN   8       // Bluetooth TX

    // Setup I/O pin modes and interrupts
    void setupPins();

#endif

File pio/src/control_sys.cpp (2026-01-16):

#include "../include/control_sys.h"

/***************************************************************/

// Motors previous position
long mot1PrevPos = 0;
long mot2PrevPos = 0;

// Motor position and velocity measurement
// mot1_pos, mot2_pos, (m1_vel, m2_vel)
static int motMeas[2] = {0};

/***************************************************************/

// Actuation signal array
// mot1_spd, mot2_spd, mot1_dir, mot2_dir
static int motAct[4] = {0};

/***************************************************************/
// PID state variables for each controller
static float pos_error_prev = 0;      // Previous position error (for derivative)
static float pos_integral = 0;        // Accumulated position error (for integral)

static float bal_error_prev = 0;      // Previous balance error
static float bal_integral = 0;        // Accumulated balance error

static float hdg_error_prev = 0;      // Previous heading error
static float hdg_integral = 0;        // Accumulated heading error

// Anti-windup limits for integral terms
#define POS_INTEGRAL_MAX 100.0f
#define BAL_INTEGRAL_MAX 50.0f
#define HDG_INTEGRAL_MAX 100.0f

/***************************************************************/
// PID position controller - controls forward/backward movement setpoint
float positionControl(float *imuPtr, float *posParamPtr, bool printData){
    // IMUptr: roll, pitch, yaw, timestamp, elapsed_time (milliseconds)
    // POSptr_param: setPos, posKP, posKI, posKD
    
    // Controller outputs (local variables, not static)
    
    float dt = imuPtr[4] / 1000.0f;  // Convert ms to seconds
    if(dt <= 0) dt = 0.001f;          // Prevent division by zero
    
    float setPos = posParamPtr[0];
    float Kp = posParamPtr[1];
    float Ki = posParamPtr[2];
    float Kd = posParamPtr[3];
    
    // Position error (difference from setpoint)
    float pos_error = setPos - 0;  // setPos is velocity target (0 for balance point)
    
    // Proportional term
    float pos_P = Kp * pos_error;
    
    // Integral term with anti-windup
    pos_integral += pos_error * dt;
    if(pos_integral > POS_INTEGRAL_MAX) pos_integral = POS_INTEGRAL_MAX;
    if(pos_integral < -POS_INTEGRAL_MAX) pos_integral = -POS_INTEGRAL_MAX;
    float pos_I = Ki * pos_integral;
    
    // Derivative term
    float pos_D = 0;
    if(dt > 0) pos_D = Kd * (pos_error - pos_error_prev) / dt;
    pos_error_prev = pos_error;
    
    // Sum all terms and return
    float posOut = pos_P + pos_I + pos_D;
    
    return posOut;
}

// PID balance controller - core stabilisation controller
float balanceControl(float *imuPtr, float *balParamPtr, float posOut, bool printData){
    // IMUptr: roll, pitch, yaw, timestamp, elapsed_time
    // BALptr_param: setBal, balKP, balKI, balKD
    // POS_out: balance offset from position controller
    
    float dt = imuPtr[4] / 1000.0f;  // Convert ms to seconds
    if(dt <= 0) dt = 0.001f;
    
    float setBal = balParamPtr[0];
    float Kp = balParamPtr[1];
    float Ki = balParamPtr[2];
    float Kd = balParamPtr[3];
    
    // Pitch angle is the balance error (want pitch near 0)
    // Add position offset to create forward/backward lean
    float pitch = imuPtr[1];  // Current pitch angle
    float bal_setpoint = setBal + posOut;  // Add position adjustment
    float bal_error = bal_setpoint - pitch;
    
    // Proportional term
    float bal_P = Kp * bal_error;
    
    // Integral term with anti-windup
    bal_integral += bal_error * dt;
    if(bal_integral > BAL_INTEGRAL_MAX) bal_integral = BAL_INTEGRAL_MAX;
    if(bal_integral < -BAL_INTEGRAL_MAX) bal_integral = -BAL_INTEGRAL_MAX;
    float bal_I = Ki * bal_integral;
    
    // Derivative term (also adds gyro feedback for stability)
    float bal_D = Kd * (bal_error - bal_error_prev) / dt;
    bal_error_prev = bal_error;
    
    // Sum all terms and return
    float balOut = bal_P + bal_I + bal_D;
    
    return balOut;
}

// PID heading controller - yaw/rotation control
float headingControl(float *imuPtr, float *hdgParamPtr, bool printData){
    // IMUptr: roll, pitch, yaw, timestamp, elapsed_time
    // HDGptr_param: setHdg, hdgKP, hdgKI, hdgKD
    
    float dt = imuPtr[4] / 1000.0f;  // Convert ms to seconds
    if(dt <= 0) dt = 0.001f;
    
    float setHdg = hdgParamPtr[0];
    float Kp = hdgParamPtr[1];
    float Ki = hdgParamPtr[2];
    float Kd = hdgParamPtr[3];
    
    // Heading error (difference from desired yaw)
    float yaw = imuPtr[2];  // Current yaw angle
    float hdg_error = setHdg - yaw;
    
    // Proportional term
    float hdg_P = Kp * hdg_error;
    
    // Integral term with anti-windup
    hdg_integral += hdg_error * dt;
    if(hdg_integral > HDG_INTEGRAL_MAX) hdg_integral = HDG_INTEGRAL_MAX;
    if(hdg_integral < -HDG_INTEGRAL_MAX) hdg_integral = -HDG_INTEGRAL_MAX;
    float hdg_I = Ki * hdg_integral;
    
    // Derivative term
    float hdg_D = Kd * (hdg_error - hdg_error_prev) / dt;
    hdg_error_prev = hdg_error;
    
    // Sum all terms and return
    float hdgOut = hdg_P + hdg_I + hdg_D;
    
    return hdgOut;
}
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

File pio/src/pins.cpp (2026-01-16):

#include "../include/pins.h"

void setupPins(){
    // Motors
    pinMode(MOT1_A, OUTPUT); // Motor 1, phase A
    pinMode(MOT1_B, OUTPUT); // Motor 1, phase B
    pinMode(MOT2_A, OUTPUT); // Motor 2, phase A
    pinMode(MOT2_B, OUTPUT); // Motor 2, phase B
    
    // Encoders
    pinMode(ENC1_A, INPUT);  // Motor 1 encoder, phase A
    pinMode(ENC1_B, INPUT);  // Motor 1 encoder, phase B
    pinMode(ENC2_A, INPUT);  // Motor 2 encoder, phase A
    pinMode(ENC2_B, INPUT);  // Motor 2 encoder, phase B
    
    // Bluetooth
    pinMode(BT_RX_PIN, INPUT);  // Bluetooth RX
    pinMode(BT_TX_PIN, OUTPUT); // Bluetooth TX

    // Interrupts
    attachInterrupt(digitalPinToInterrupt(ENC1_A), inc1, RISING);    // Motor 1 encoder
    attachInterrupt(digitalPinToInterrupt(ENC2_A), inc2, RISING);    // Motor 2 encoder
}

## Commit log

2025-11-16 Included schematic
    [TWSBR.kicad_pcb, TWSBR.kicad_sch]
2026-01-14 stability improvements, finished controller
    [IMU_functions.cpp, control_sys.cpp, control_sys.h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]
